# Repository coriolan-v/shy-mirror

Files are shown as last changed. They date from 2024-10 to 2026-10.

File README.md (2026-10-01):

# Shy mirror firmware

Adafruit ItsyBitsy M4 Express (SAMD51G19A), built with PlatformIO.
Open Firmware/shy-mirror-fw in VS Code, or run these commands from that folder:

```powershell
pio run
pio run -t upload
pio device monitor
```

The serial monitor uses 115200 baud, local echo and send-on-enter.
Close it before uploading.

## Fixed sensor positions

The order is hardcoded in Firmware/shy-mirror-fw/include/Config.h.
No hand-mapping procedure or saved flash map is required after upload.

| Physical sensor / position | XSHUT pin | Internal hardware ID |
| --- | --- | --- |
| 1 | 9 | 4 |
| 2 | A3 | 3 |
| 3 | A2 | 2 |
| 4 | A1 | 1 |
| 5 | A0 | 0 |
| 6 | 12 | 7 |
| 7 | 11 | 6 |
| 8 | 10 | 5 |

Pin 10 (physical sensor 8, hardware ID 5) remains disabled via disabledSensorMask.
To enable it, set that mask to 0 and upload. All eight physical positions remain
45 degrees apart; disabling a sensor does not renumber the others.
The sensors command reports readings in the physical order above.

## Automatic interactive mode

On startup the firmware initializes sensors and homes the mirror. If the Hall
sensor is already active LOW for 15 ms, homing movement is skipped. Otherwise it
seeks the Hall reference in the positive motor direction.

After successful homing, it prints:
Interactive mode active: mirror moves opposite the detected person.

Home corresponds to physical position 5.5, halfway between positions 5 and 6.
A valid smoothed distance below 1,000 mm detects occupancy. Once the nearest
position remains selected for 100 ms, the mirror moves 180 degrees opposite it,
using the shorter rotation. For example, person at 1 -> mirror at 5, person at
5 -> mirror at 1. The nearest distance wins if several positions are occupied.
Distance sensors can also detect nearby furniture; they do not identify humans.

NO TARGET / weak returns are normal in empty space and never trigger movement.
Stale readings, communication errors and other invalid ranges are ignored for
person detection. When no person is detected, the mirror holds its last position.

Sensors continue updating during automatic movement, and a new confirmed person
position retargets the motor immediately. AccelStepper preserves speed and
decelerates before reversing; the coordinate is normalized only when at rest.
Repeated detections of the same target do not restart the move or its timeout.

TC3 on the SAMD51 services STEP pulses at 40 kHz, independently of foreground
I2C/serial work. TC3 is reserved for the motor; do not reuse it for PWM or another
library. If foreground execution stalls for more than 250 ms, the interrupt
disables the driver and stops pulses; home again after resolving the fault.
Sensor reads remain paused during homing/calibration and the manual motor test.
Coils remain enabled after successful homing and automatic movement.

stop/cancel, failed movement and motor tests disable automatic behavior.
Send home to resume. Homing is bounded by 180 seconds and 64,000 pulses.

## Configuration

Edit Firmware/shy-mirror-fw/include/Config.h, then rebuild/upload.

| Setting | Purpose |
| --- | --- |
| DEBUG | true shows detection distance and uptime when a new movement starts |
| disabledSensorMask | Disabled hardware IDs; currently bit 5 / physical sensor 8 |
| sensorHardwareIdByPosition | Fixed position-to-hardware-ID order |
| homeOnStartup | true starts homing automatically |
| mirrorStepsPerRevolution | Motor STEP pulses per full mirror turn, measured as 15,999 |
| motorPositionDirection | +1 follows increasing positions; -1 reverses them |
| mirrorMoveSpeed | Maximum automatic/test speed, pulses per second |
| mirrorAcceleration | Automatic/test acceleration, pulses per second squared |
| homingSpeed | Constant homing speed, pulses per second |
| sensorTimingBudgetUs | 20,000 us per measurement in Short mode |
| sensorPeriodMs | 30 ms continuous measurement period |
| personConfirmMs | 100 ms stable target confirmation |
| sensorStaleMs | Discard samples older than 100 ms |
| sensorSmoothingDivisor | 2 uses 50% of the new reading (was 10%) |

The configured revolution count is the Hall-measured value of 15,999 pulses. Optional motor-only
calibrate measures one revolution using successive Hall activations. It is
separate from the removed sensor-mapping setup and is never required at startup.
It requires exactly one Hall activation per mirror revolution. Copy its printed
result into mirrorStepsPerRevolution to retain it across resets.
If positive rotation goes opposite to increasing physical positions, use -1 for
motorPositionDirection.

Detection thresholds are lowerTreshold in src/Sensors.cpp, indexed by position.
The faster sensor settings use Short mode (about 1.3 m maximum range) for the
existing 1 m detection threshold. More distant surfaces may report NO TARGET.
Short mode supports a 20 ms budget; use at least 33 ms if changing back to Long
mode. These limits are documented by the
[Pololu library](https://github.com/pololu/vl53l1x-arduino#library-reference).

The configured motor rates are preserved at 3,200 pulses/s and 6,400 pulses/s^2.
Timer-based servicing still needs a bench check for pulse timing, smooth
reversals and missed steps at the mirror's actual mechanical load.

## Serial commands

| Command | Result |
| --- | --- |
| order | Show the fixed sensor positions; map is a read-only alias |
| sensors | Report distances, health, disabled sensors and Hall state |
| home | Home and automatically enter interactive mode |
| stop / cancel | Stop and disable automatic movement until home |
| motor | Test 400 pulses forward/back; home again afterwards |
| calibrate | Optional motor revolution measurement; does not change sensor order |
| help | List commands |

## Wiring

STEP = MISO, DIR = MOSI, ENABLE = pin 5 (active HIGH), Hall = SCK
(active LOW, internal pull-up). I2C addresses remain assigned by internal
hardware ID from 0x2A through 0x31.

If the motor does not move, check driver power, common ground, ENABLE polarity,
STEP/DIR wiring, coil pairs and driver current. Pulses do not prove physical
rotation. Reset after repairing a sensor that failed initialization.

## Validation

Compile-time checks cover the fixed sensor order and opposite-position math:

```text
arm-none-eabi-g++ -std=c++11 -Iinclude -fsyntax-only test/fixed_sensor_order.cpp test/motion_math.cpp
```

Bench-check homing, moving a target between positions while the motor is
turning, smooth reversal, empty-space readings, motor direction and stop. The firmware has been compiled; physical movement requires verification.

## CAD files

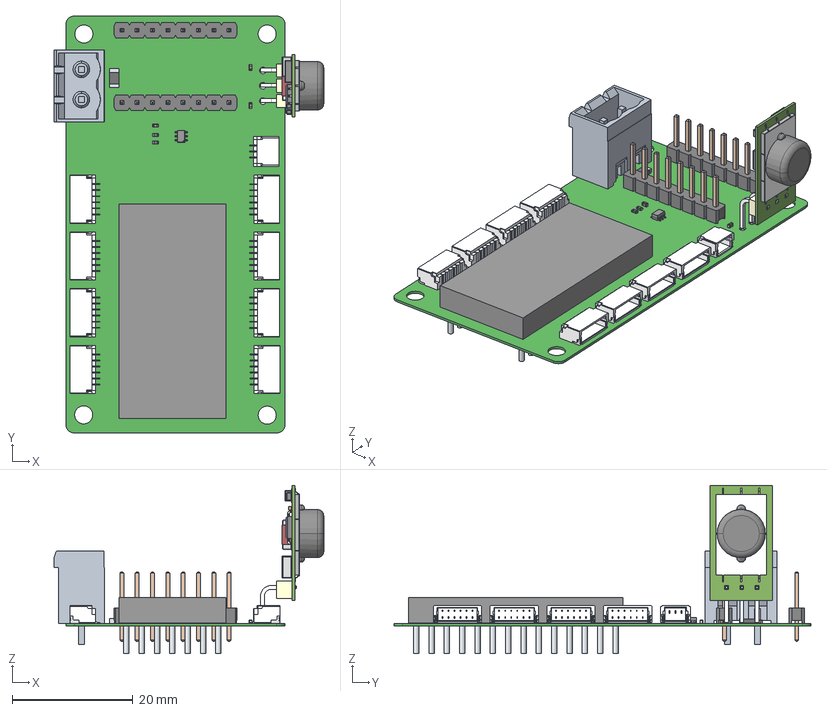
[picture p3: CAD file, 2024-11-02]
PCB/Shy-Mirror-revB/Shy-Mirror-master-revB.step
44.7 x 69.1 x 27.9 mm
Leads x 33
solidBody
Terminal
solidTop
6130xx11121_PIN x 16
PinsArrayLR
term1 x 2
term2 x 2

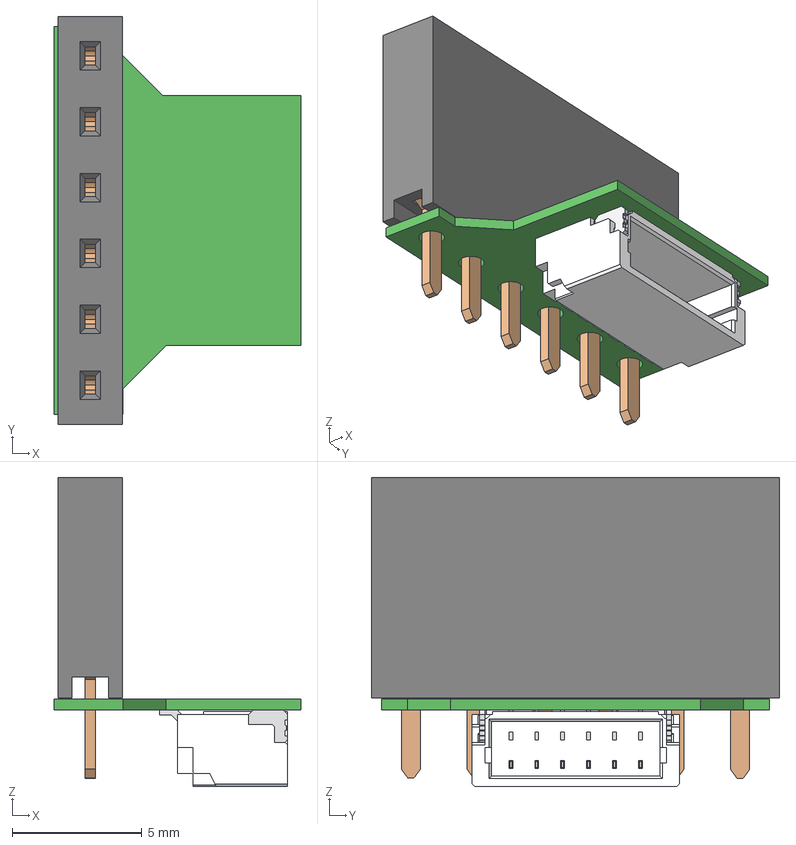
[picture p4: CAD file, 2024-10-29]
PCB/Shy-mirror-sensor/shy-mirror-sensor-revA.step
9.53 x 15.7 x 11.9 mm
6130xx11821_PIN x 6

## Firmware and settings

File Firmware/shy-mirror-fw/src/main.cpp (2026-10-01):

#include "Firmware.h"
#include "Config.h"
// Adafruit ItsyBitsy M4 Express. Serial Monitor: 115200 baud, newline.
#include <string.h>

void printHelp();
void handleCommands();

void setup() {
  Serial.begin(115200);
  initMotor();
  initSensors();
  printSensorOrder();
  printHelp();
  if (homeOnStartup) motorHoming();
}

void loop() {
  handleCommands();
  runMotor();
  // The timer services STEP pulses during sensor reads and live retargeting.
  // Keep homing/test measurements isolated from sensor diagnostics.
  if (motorBusy() && !motorHomed()) return;
  readSensors();
  detectPeopleZones();
}

void printHelp() {
  Serial.println("Commands: order, sensors, motor, home, stop, calibrate, help");
}

void handleCommands() {
  static char command[24];
  static uint8_t length = 0;
  static bool overflow = false;
  while (Serial.available()) {
    char c = Serial.read();
    if (c == '\r' || c == '\n') {
      if (overflow) Serial.println("Command too long; ignored.");
      else if (length) {
        command[length] = '\0';
        if (!strcmp(command, "help")) printHelp();
        else if (!strcmp(command, "order") || !strcmp(command, "map")) printSensorOrder();
        else if (!strcmp(command, "cancel") || !strcmp(command, "stop")) {
          stopMotor();
        }
        else if (motorBusy())
          Serial.println("Motor moving. Use stop first.");
        else if (!strcmp(command, "sensors")) testSensors();
        else if (!strcmp(command, "motor")) testMotor();
        else if (!strcmp(command, "home")) motorHoming();
        else if (!strcmp(command, "calibrate")) calibrateMotor();
        else Serial.println("Unknown command. Type help.");
      }
      length = 0;
      overflow = false;
    } else if (length < sizeof(command) - 1) command[length++] = c;
    else overflow = true;
  }
}

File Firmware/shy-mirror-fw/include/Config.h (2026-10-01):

#pragma once
#include <stdint.h>
#include "MotionMath.h"

// DEBUG LOGGING: true = show detection details; false = hide them.
// Rebuild and upload after changing this flag.
constexpr bool DEBUG = true;

// Hardware IDs from 'sensors', not zone numbers.
// ID:      0   1   2   3   4   5   6   7
// XSHUT:  A0  A1  A2  A3   9  10  11  12
// Use 0 for all enabled; (1u << 5) | (1u << 6) disables IDs 5 and 6.
constexpr uint8_t disabledSensorMask = (1u << 5);
static_assert(disabledSensorMask != 0xFF, "At least one sensor must be enabled");

// Fixed physical positions 1-8 -> hardware IDs above.
// Position:  1   2   3   4   5   6   7   8
// XSHUT:     9  A3  A2  A1  A0  12  11  10
// Pin 10 is physical position 8; its existing disabled bit remains in effect.
constexpr uint8_t sensorHardwareIdByPosition[physicalZoneCount] = {4, 3, 2, 1, 0, 7, 6, 5};

// Automatically start bounded, nonblocking homing after initialization.
constexpr bool homeOnStartup = true;
// Return to the established home position after one minute without a detection.
constexpr uint32_t returnHomeAfterMs = 60000;

// Eight physical positions remain 45 degrees apart, including disabled positions.
// Measured with the Hall sensor: 15,999 STEP pulses per mirror revolution.
constexpr long mirrorStepsPerRevolution = 15999;
// +1 if positive motor rotation follows increasing physical positions; otherwise -1.
constexpr int motorPositionDirection = 1;
constexpr long mirrorMoveSpeed = 2500;
constexpr long mirrorAcceleration = 3200;
constexpr long homingSpeed = 1300;
static_assert(mirrorStepsPerRevolution >= 800 && mirrorStepsPerRevolution <= 64000,
              "Mirror revolution must be within calibration limits");
static_assert(motorPositionDirection == 1 || motorPositionDirection == -1,
              "Motor direction must be +1 or -1");

// Fast tracking settings required by the sensor loop.
constexpr uint32_t sensorTimingBudgetUs = 20000;
constexpr uint32_t sensorPeriodMs = 30;
constexpr uint32_t personConfirmMs = 100;
constexpr uint32_t sensorStaleMs = 100;
constexpr int sensorSmoothingDivisor = 2;
static_assert(mirrorMoveSpeed > 0 && mirrorMoveSpeed <= 10000, "Speed must fit 40 kHz step service");
static_assert(mirrorAcceleration > 0 && homingSpeed > 0 && homingSpeed <= 10000, "Invalid motor rates");
static_assert(sensorTimingBudgetUs >= 20000 && sensorPeriodMs * 1000 > sensorTimingBudgetUs,
              "Sensor period must exceed Short-mode timing budget");
static_assert(sensorSmoothingDivisor >= 1, "Smoothing divisor must be positive");

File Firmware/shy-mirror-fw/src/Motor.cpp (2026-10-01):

#include "Firmware.h"
#include "Config.h"
#include "MotionMath.h"
#include "InterruptStepper.h"
#include "HallReference.h"
#include <stdio.h>

#define stepPin MISO
#define directionPin MOSI
#define enPin 5
#define HallSensor SCK

// Preserve the working driver polarity.
const uint8_t motorEnableLevel = HIGH;
InterruptStepper stepper(stepPin, directionPin);
enum { IDLE, TEST_OUT, TEST_BACK, HOME_SEEK, AUTO_MOVE, HOME_RELEASE, CAL_RELEASE, CAL_SEEK, HOME_CHECK };
volatile uint8_t motorMode = IDLE;
uint32_t motorStartedAt = 0;
uint32_t lastHomingReportAt = 0;
uint32_t hallStateSince = 0;
int previousHall = HIGH;
long phaseStart = 0;
long testStart = 0;
long mirrorSteps = mirrorStepsPerRevolution;
bool homed = false;
bool calibrating = false;

volatile uint32_t motorHeartbeatUs = 0;
volatile bool motorServiceFault = false;
long automaticTargetAngle = -1;
uint32_t lastPersonSeenAt = 0;
bool inactivityReturnRequested = false;
HallReference hallReference;
long hallReferenceAngle = 0;
volatile long homingHallEdge = 0;
volatile bool homingHallEdgeKnown = false;

extern "C" void TC3_Handler() {
  if (!(TC3->COUNT16.INTFLAG.reg & TC_INTFLAG_MC0)) return;
  TC3->COUNT16.INTFLAG.reg = TC_INTFLAG_MC0;
  const uint8_t mode = motorMode;
  if (motorServiceFault) return;
  long edgePosition;
  if (hallReference.update(digitalRead(HallSensor) == LOW, micros(),
                           stepper.currentPosition(), stepper.motionDirection(), edgePosition)) {
    if (mode == HOME_SEEK || mode == CAL_SEEK) {
      homingHallEdge = edgePosition;
      homingHallEdgeKnown = true;
    } else if (mode == AUTO_MOVE && homed) {
      // Include steps taken during debounce; only correct the edge's error.
      stepper.correctPosition(shortestStepDelta(edgePosition, hallReferenceAngle, mirrorSteps));
    }
  }
  if (mode == IDLE || mode == HOME_CHECK) return;
  // Stop independently if foreground I2C/USB gets stuck. Main reports the fault.
  if (uint32_t(micros() - motorHeartbeatUs) > 250000UL) {
    motorServiceFault = true;
    digitalWrite(enPin, motorEnableLevel == LOW ? HIGH : LOW);
    return;
  }
  const bool constantSpeed = mode == HOME_SEEK || mode == HOME_RELEASE ||
    mode == CAL_RELEASE || mode == CAL_SEEK;
  stepper.service(constantSpeed);
}

void initStepTimer() {
  // Reserve TC3 for 40 kHz step servicing. GCLK0 follows the 120 MHz CPU clock.
  NVIC_DisableIRQ(TC3_IRQn);
  MCLK->APBBMASK.reg |= MCLK_APBBMASK_TC3;
  GCLK->PCHCTRL[TC3_GCLK_ID].reg = 0;
  while (GCLK->PCHCTRL[TC3_GCLK_ID].reg & GCLK_PCHCTRL_CHEN) {}
  GCLK->PCHCTRL[TC3_GCLK_ID].reg = GCLK_PCHCTRL_GEN_GCLK0 | GCLK_PCHCTRL_CHEN;
  while (!(GCLK->PCHCTRL[TC3_GCLK_ID].reg & GCLK_PCHCTRL_CHEN)) {}
  TC3->COUNT16.CTRLA.reg = TC_CTRLA_SWRST;
  while (TC3->COUNT16.SYNCBUSY.reg || TC3->COUNT16.CTRLA.bit.SWRST) {}
  TC3->COUNT16.CTRLA.reg = TC_CTRLA_MODE_COUNT16 | TC_CTRLA_PRESCALER_DIV1;
  while (TC3->COUNT16.SYNCBUSY.reg) {}
  TC3->COUNT16.WAVE.reg = TC_WAVE_WAVEGEN_MFRQ;
  TC3->COUNT16.CC[0].reg = F_CPU / 40000UL - 1;
  while (TC3->COUNT16.SYNCBUSY.reg) {}
  TC3->COUNT16.INTFLAG.reg = TC_INTFLAG_MC0;
  TC3->COUNT16.INTENSET.reg = TC_INTENSET_MC0;
  NVIC_SetPriority(TC3_IRQn, 2);
  NVIC_ClearPendingIRQ(TC3_IRQn);
  NVIC_EnableIRQ(TC3_IRQn);
  TC3->COUNT16.CTRLA.reg |= TC_CTRLA_ENABLE;
  while (TC3->COUNT16.SYNCBUSY.reg) {}
}



int readHallSensor() { return digitalRead(HallSensor); }
bool motorBusy() { return motorMode != IDLE; }
bool motorHomed() { return homed; }

void resetHallDebounce() {
  previousHall = readHallSensor();
  hallStateSince = millis();
}

bool hallStable(int level) {
  int state = readHallSensor();
  if (state != previousHall) {
    previousHall = state;
    hallStateSince = millis();
  }
  return state == level && millis() - hallStateSince >= 15;
}

void initMotor() {
  pinMode(HallSensor, INPUT_PULLUP);
  digitalWrite(enPin, motorEnableLevel == LOW ? HIGH : LOW);
  pinMode(enPin, OUTPUT);
  stepper.setMinPulseWidth(3);
  stepper.setMaxSpeed(mirrorMoveSpeed);
  stepper.setAcceleration(mirrorAcceleration);
  motorHeartbeatUs = micros();
  hallReference.reset(readHallSensor() == LOW, micros());
  initStepTimer();
}

void stopMotor() {
  motorMode = IDLE;
  motorServiceFault = false;
  automaticTargetAngle = -1;
  homed = false; // Disabled coils or interrupted motion can lose the reference.
  calibrating = false;
  stepper.setCurrentPosition(stepper.currentPosition());
  digitalWrite(enPin, motorEnableLevel == LOW ? HIGH : LOW);
}

void testMotor() {
  stopMotor();
  testStart = stepper.currentPosition();
  motorStartedAt = millis();
  motorHeartbeatUs = micros();
  digitalWrite(enPin, motorEnableLevel);
  stepper.moveTo(testStart + 400);
  motorMode = TEST_OUT;
  Serial.println("Motor test: 400 pulses forward and back. Send home afterwards.");
}

void beginHoming(bool measureRevolution) {
  stopMotor();
  {
    StepperLock lock;
    homingHallEdgeKnown = false;
    hallReference.reset(readHallSensor() == LOW, micros());
  }
  calibrating = measureRevolution;
  motorStartedAt = millis();
  motorHeartbeatUs = micros();
  lastHomingReportAt = motorStartedAt;
  phaseStart = stepper.currentPosition();
  digitalWrite(enPin, motorEnableLevel);
  stepper.setSpeed(homingSpeed);
  resetHallDebounce();
  if (readHallSensor() == LOW) {
    motorMode = measureRevolution ? HOME_RELEASE : HOME_CHECK;
    Serial.println(measureRevolution ?
      "Calibration: clearing Hall to establish a repeatable edge." :
      "Hall active: checking home without moving.");
  } else {
    motorMode = HOME_SEEK;
    Serial.println("Homing positive: seeking Hall.");
  }
  Serial.println("stop cancels. Maximum 180 seconds / 64000 pulses.");
}

void motorHoming() {
  beginHoming(false);
}

void calibrateMotor() {
  beginHoming(true);
  Serial.println("CALIBRATE: find home, then measure one full turn between Hall activations.");
  Serial.println("Requires one Hall activation per mirror revolution.");
  Serial.println("Observe whether this motion follows increasing physical positions.");
}
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

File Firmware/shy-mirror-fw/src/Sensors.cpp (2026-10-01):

#include "Config.h"
#include "Firmware.h"
#include <Wire.h>
#include <VL53L1X.h>

const uint8_t sensorCount = physicalZoneCount;
const uint8_t xshutPins[sensorCount] = { A0, A1, A2, A3, 9, 10, 11, 12 };
const char * const pinNames[sensorCount] = { "A0", "A1", "A2", "A3", "9", "10", "11", "12" };
const uint32_t sampleMaxAgeMs = sensorStaleMs;
VL53L1X sensors[sensorCount];
bool sensorPresent[sensorCount] = {};
bool sensorValid[sensorCount] = {};
bool sensorReadHealthy[sensorCount] = {};
bool sensorHasSample[sensorCount] = {};
bool meanInitialized[sensorCount] = {};
uint32_t sampleAt[sensorCount] = {};
uint16_t sensorReadRaw[sensorCount] = {};
int sensorReadMean[sensorCount] = {};
int lowerTreshold[sensorCount] = {1000,1000,1000,1000,1000,1000,1000,1000};
bool sensorDisabled(uint8_t id) {
  return (disabledSensorMask & (1u << id)) != 0;
}

void initSensors() {
  Wire.begin();
  Wire.setClock(400000);
  for (uint8_t i = 0; i < sensorCount; ++i) {
    pinMode(xshutPins[i], OUTPUT);
    digitalWrite(xshutPins[i], LOW);
  }
  delay(10);
  for (uint8_t i = 0; i < sensorCount; ++i) {
    if (sensorDisabled(i)) continue; // Keep disabled sensors in reset.
    pinMode(xshutPins[i], INPUT); // Release XSHUT; do not drive it high.
    delay(10);
    sensors[i].setTimeout(100);
    if (sensors[i].init()) {
      sensors[i].setAddress(0x2A + i);
      Wire.beginTransmission(0x2A + i);
      if (Wire.endTransmission() == 0 &&
          sensors[i].setDistanceMode(VL53L1X::Short) &&
          sensors[i].setMeasurementTimingBudget(sensorTimingBudgetUs)) {
        sensors[i].startContinuous(sensorPeriodMs);
        sensorPresent[i] = sensors[i].last_status == 0;
      }
    }
    if (!sensorPresent[i]) {
      // Isolate failed devices to avoid address collisions at 0x29.
      pinMode(xshutPins[i], OUTPUT);
      digitalWrite(xshutPins[i], LOW);
      Serial.print("Sensor init FAIL, hardware ID "); Serial.println(i);
    }
  }
}

void readSensors() {
  static uint32_t lastPoll = 0;
  if (millis() - lastPoll < 2) return;
  lastPoll = millis();
  for (uint8_t i = 0; i < sensorCount; ++i) {
    if (sensorDisabled(i) || !sensorPresent[i]) continue;
    bool ready = sensors[i].dataReady();
    if (sensors[i].last_status != 0) {
      sensorValid[i] = false;
      sensorReadHealthy[i] = false;
      meanInitialized[i] = false;
      continue;
    }
    if (!ready) continue;
    bool wasFresh = sensorHasSample[i] && millis() - sampleAt[i] <= sampleMaxAgeMs;
    sensorReadRaw[i] = sensors[i].read(false);
    sensorHasSample[i] = true;
    sampleAt[i] = millis();
    sensorReadHealthy[i] = !sensors[i].timeoutOccurred() && sensors[i].last_status == 0;
    sensorValid[i] = sensorReadHealthy[i] &&
      sensors[i].ranging_data.range_status == VL53L1X::RangeValid;
    if (sensorValid[i]) {
      if (!meanInitialized[i] || !wasFresh) sensorReadMean[i] = sensorReadRaw[i];
      else sensorReadMean[i] += (int(sensorReadRaw[i]) - sensorReadMean[i]) / sensorSmoothingDivisor;
      meanInitialized[i] = true;
    } else meanInitialized[i] = false;
  }
}

bool sensorFresh(uint8_t i) {
  return sensorPresent[i] && sensorHasSample[i] && millis() - sampleAt[i] <= sampleMaxAgeMs;
}

bool sensorNoTarget(uint8_t id) {
  return sensorFresh(id) && sensorReadHealthy[id] &&
    sensors[id].ranging_data.range_status == VL53L1X::SignalFail;
}

void testSensors() {
  Serial.println("Sensor check: NO TARGET is normal in open space; use a card to verify distance.");
  for (uint8_t slot = 0; slot < sensorCount; ++slot) {
    uint8_t i = sensorHardwareIdByPosition[slot];
    Serial.print("Sensor "); Serial.print(slot + 1); Serial.print(" / ");
    Serial.print("ID "); Serial.print(i); Serial.print(" XSHUT "); Serial.print(pinNames[i]);
    Serial.print(" addr 0x"); Serial.print(0x2A + i, HEX);
    if (sensorDisabled(i)) {
      Serial.println(" DISABLED in Config.h");
      continue;
    }
    Wire.beginTransmission(0x2A + i);
    bool ack = Wire.endTransmission() == 0;
    if (!sensorPresent[i] || !ack) Serial.println(" FAIL: missing/init/I2C");
    else if (!sensorFresh(i)) Serial.println(" FAIL: no fresh reading");
    else if (!sensorReadHealthy[i]) Serial.println(" FAIL: I2C/read error");
    else if (sensorNoTarget(i)) Serial.println(" OK: NO TARGET (open space / weak return)");
    else {
      Serial.print(sensorValid[i] ? " PASS: " : " CHECK TARGET: ");
      Serial.print(sensorReadRaw[i]); Serial.print(" mm, ");
      Serial.println(VL53L1X::rangeStatusToString(sensors[i].ranging_data.range_status));
    }
  }
  Serial.print("Hall input (LOW=active): "); Serial.println(readHallSensor());
}

void printSensorOrder() {
  for (uint8_t slot = 0; slot < sensorCount; ++slot) {
    uint8_t id = sensorHardwareIdByPosition[slot];
    Serial.print("Physical position "); Serial.print(slot + 1);
    Serial.print(" -> ID "); Serial.print(id);
    if (sensorDisabled(id)) Serial.print(" DISABLED");
    Serial.print(" / XSHUT "); Serial.print(pinNames[id]);
    Serial.print(" / I2C 0x"); Serial.println(0x2A + id, HEX);
  }
}

void detectPeopleZones() {
  static uint32_t lastCheck = 0;
  static uint32_t candidateAt = 0;
  static uint8_t personCandidate = 0;
  if (!motorHomed()) { personCandidate = 0; return; }
  if (millis() - lastCheck < 10) return;
  lastCheck = millis();
  uint8_t nearest = 0;
  int nearestMm = 32767;
  for (uint8_t slot = 0; slot < sensorCount; ++slot) {
    uint8_t id = sensorHardwareIdByPosition[slot];
    if (sensorDisabled(id) || sensorNoTarget(id) || !sensorFresh(id) || !sensorValid[id]) continue;
    if (sensorReadMean[id] < lowerTreshold[slot] && sensorReadMean[id] < nearestMm) {
      nearest = slot + 1;
      nearestMm = sensorReadMean[id];
    }
  }
  // Any close valid reading resets inactivity, even before zone confirmation.
  updatePersonPresence(nearest != 0);
  if (nearest == 0) { personCandidate = 0; return; }
  if (nearest != personCandidate) {
    personCandidate = nearest;
    candidateAt = millis();
    return;
  }
  if (millis() - candidateAt < personConfirmMs) return; // Reject passing noise and unstable targets.
  moveOppositePosition(nearest, nearestMm);
}

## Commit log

2024-10-09 init servo test
2024-10-16 added stl
    [Ring.stl, Step - Nema 17 - 17HS3401 - Usongshine.SLDPRT, XLPulley.stl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]
2024-10-22 3d model v1
    [1-big-cog.stp, 2-small-cog.stp, 3-motor-slipring-support.stp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]
2024-10-22 3d model update
    [1-big-cog.stp, 2-small-cog.stp, 3-motor-slipring-support.stp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]
2024-10-22 new exports
    [1-big-cog.stp, 2-bottom.stp, 2-small-cog.stp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]
2024-10-26 small cog b2
    [1-big-cog.stp, 2-bottom.stp, 3-small-cog-v2.3dm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]
2024-10-26 code for sensors
2024-10-26 simplify sensors
2024-10-27 code axxelstepper + hall effect
2024-10-27 code for multiple sensors
2024-10-27 pcbs master and sensor
    [Shy-Mirror-master-revA.PrjPcb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]
2024-10-28 added pcb again
    [Shy-Mirror-master-revA.PrjPcb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]
2024-10-28 added 3d
    [part2-bottom.stl, part2-bottom.stp]
2024-10-29 added rhino
    [Shy-Mirror-master-revB.GBL, Shy-Mirror-master-revB.GBO, Shy-Mirror-master-revB.GBP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]
2024-10-29 update cad
    [Shy-Mirror-master-revB.step, TOF400C.SLDPRT, TOF400C.STEP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]
2024-10-29 update 3d
    [3-small-cog-v3.stp, TOF400C.SLDPRT, TOF400C.STEP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]
2024-10-30 update sensor
    [TOF400C.SLDPRT, TOF400C.STEP, TOF400C.STL]
2024-11-03 final cad
    [part1-big-cog.stp, part2-bottom.stp, part3-small-cog.stp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]
2026-09-28 added calibration
2026-09-29 removed 3d
    [1-big-cog.stp, 2-bottom.stp, 3-small-cog-v3.stp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]
